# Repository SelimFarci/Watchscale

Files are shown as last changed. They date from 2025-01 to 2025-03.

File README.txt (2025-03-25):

# 🧭 DRO & DIVIDER Systems – Embedded Control Interface for Watchmaking Machinery

> Embedded systems project developed during a summer internship – ENSEA (2024)

## 📌 Project Summary

This project involved designing and prototyping two embedded control systems — a **Digital Read-Out (DRO)** interface and a **DIVIDER** motor control module — to modernize mechanical watchmaking machines, without altering their vintage aesthetic.

We developed a full-stack embedded application based on STM32 microcontrollers, including sensor data acquisition, user interface development (TouchGFX), real-time control of motors, and communication between devices.

> 💡 Non-confidential project – suitable for public sharing.

---

## 🔧 Key Features

### 🖥️ DRO System (Main Controller)
- 7” capacitive touchscreen interface
- Real-time display of axis positions (X/Y/Z)
- GUI with control functions: 
  - `ZERO`, `Ø/R`, `+/-`, spindle speed, and torque
- Interfaces: RL2IC sensors, UART, I2C, RS422

### ⚙️ DIVIDER System
- Dual stepper motor control:
  - Linear advance (motor 1)
  - Angular indexing (motor 2)
- Precision via screw/nut + endless screw systems
- Controlled from DRO board via I2C

---

## 🧠 Technical Stack

| Category | Tools / Technologies |
|---|---|
| Embedded Programming  | C, STM32CubeIDE, HAL drivers |
| GUI Development | TouchGFX |
| Microcontrollers | STM32F411xE (Nucleo), STM32H7 (Riverdi) |
| Communication | I2C, UART, RS422 |
| Signal Prototyping | Logic Analyzer, Oscilloscope, Putty |
| Hardware Design | KiCad (schematics), sensors, motors |
| Components | RS485 Click, UART Mux, Incremental encoders, NEMA 17, Riverdi 7" LCD |

---

## 🛠️ Main Contributions

✅ Designed and implemented a user-friendly GUI on STM32 using TouchGFX  
✅ Developed communication interfaces (I2C, UART, RS422) between boards and sensors  
✅ Integrated stepper motor drivers with PWM and direction control  
✅ Built functional hardware prototypes with debugging via logic analyzers  
✅ Collaborated directly with a non-technical client to translate mechanical requirements into embedded specs

---

## 📸 Screenshots

> See full PDF report with schematics, GUI designs and prototyping photos here:  
📄 [Rapport_de_projet_Watchscale.pdf](./Rapport_de_projet_Watchscale.pdf)

---

## 👨‍💻 Authors

- **Selim Farci** – Embedded Systems Engineering Student (ENSEA)  
- **Abdelkader Chambi** – Embedded Systems Engineering Student (ENSEA)  
- **Eyraud Michaël** – Internship supervisor and initiator of the project (Mécaniquement Vôtre)

---

## 🪪 License

This project is released under the **MIT License**.  
Note: proprietary hardware is subject to company use policies.

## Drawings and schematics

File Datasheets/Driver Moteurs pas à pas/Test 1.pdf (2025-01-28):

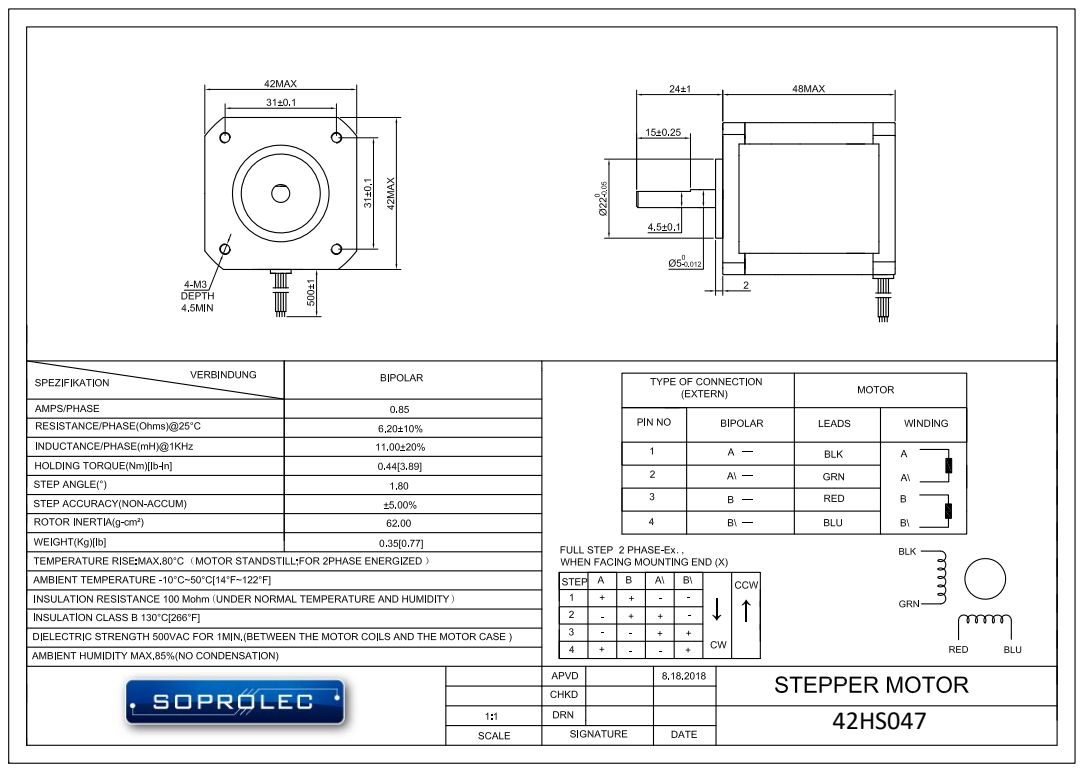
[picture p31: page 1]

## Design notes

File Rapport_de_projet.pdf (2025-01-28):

# 2A FISE Project Report

Development of a DRO and DIVIDER System

Selim FARCI, Abdelkader CHAMBI

June-August 2024

Interns: Selim Farci, AbdelKader CHAMBI Company Supervisor : Mr. Micha¨el EYRAUD University Supervisor : Mr. CHIPI

## Table of Contents

1 Introduction | 4
2 DRO and DIVIDER Systems | 5
3 SYSML and GANTT Diagrams | 7
4 Component selection | 9
5 Electrical schematic | 23
6 Graphical Interface Development | 24
7 Prototypes | 31
8 Challenges and Problem Solving | 44
9 Results and Discussions | 44
10 Conclusion | 44

10.1.1 Insufficient supervision and non-compliance with the requirements of the engineering

## 1 Introduction

### 1.1 Company Presentation

M´ecaniquement vˆotre, based in Switzerland, is a company managed by EYRAUD Michael. The company specialises in the overhaul of old industrial watchmaking systems, systems that are now coveted by various watch enthusiasts, such as collectors and watchmakers. EYRAUD Michael is a mechanic, which is why the company is first and foremost a workshop. During this project, we worked alongside other trainees, who themselves specialised in mechanics. The company does not have a CSR management system. It does, however, recycle as much as possible of its parcel boxes.

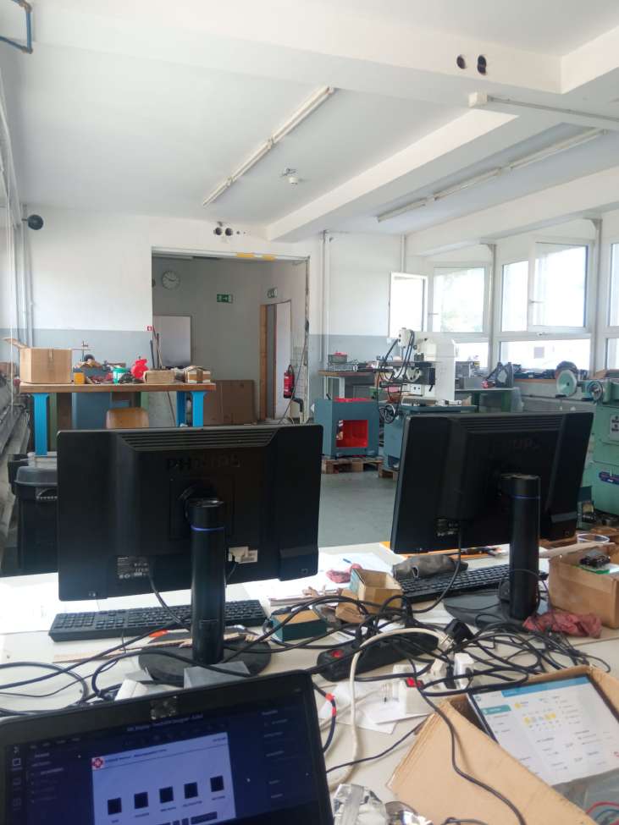
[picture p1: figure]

Figure 2: Increment sensors overview

The project assigned to us was part of this modernization effort, involving the development of a DRO system and a DIVIDER system. Although the entrepreneur was not an expert in electronics, he played a key role in financing the project and defining the requirements, which required a deep understanding of his expectations to translate these ideas into technical solutions.

### 1.2 Context and objective of the project

The objective of the project is to develop a ”DRO system and a ”DIVIDER system”.
The DRO system have to display and modificate values given by sensors and linear scales from a minimum 7” touch screen controller.
The DIVIDER system is a complementary system of the DRO system, he have to control 2 stepper motors to perform various functions.
This DRO system aims to facilitate the use of industrial watchmaking systems while preserving old industrial machines. These machines, which are highly sought after by watchmaking artisans, retain their vintage appearance as they are valuable collector’s items. Keep in mind that the price and industrial credibility are important factors for the development of this project.

## 2 DRO and DIVIDER Systems

### 2.1 The DRO system

The DRO system will be the control center and user interface panel with screen, control and switches, it have to run independently.
The system must be ready to control all other systems so the functions of all others systems must be programmed on the microprocessor.
The system must display with a graphical interface:
- Number of axes (values from RL2IC sensors)
– Function buttons - Spindle motor information.
Functions:
- ZERO: Set value to 0.
- Ø / R: Double value (Ø = Diameter) or reset to original (R = radius).
- + / -: Add or subtract a value (Show keyboard to give a value, apply, select axis).
- Spindle speed:
- Spindle torque:
- menu back

(a) Example of the graphical user interface of the MENU provided by the specifications document
(b) Example of the graphical user interface of the DRO provided by the specifications document

### 2.2 The DIVIDER system

The DIVIDER system will be a complementary system to the DRO system, Enabling control of 2 stepper motors to perform various functions.
Functioning : From the angular zero bridge and the current linear zero point. 1: Stepper motor No. 1 turns to drive a precision screw/nut system to perform a linear advance cycle including advance of a given value then return to the initial position. 2: Stepper motor No. 2 turns to drive a screw and endless wheel system, to perform angular indexing defined by a given number of divisions, applied to a given angular sector, from its current position to the next position. The angular position is controlled by an sensor (same as the DRO system) and a circular scale and must be adjusted corrected as necessary before starting a new cycle of linear motion motor 1.

Figure 4: Example of the graphical user interface of the DIVIDER provided by the specifications document

## 3 SYSML and GANTT Diagrams

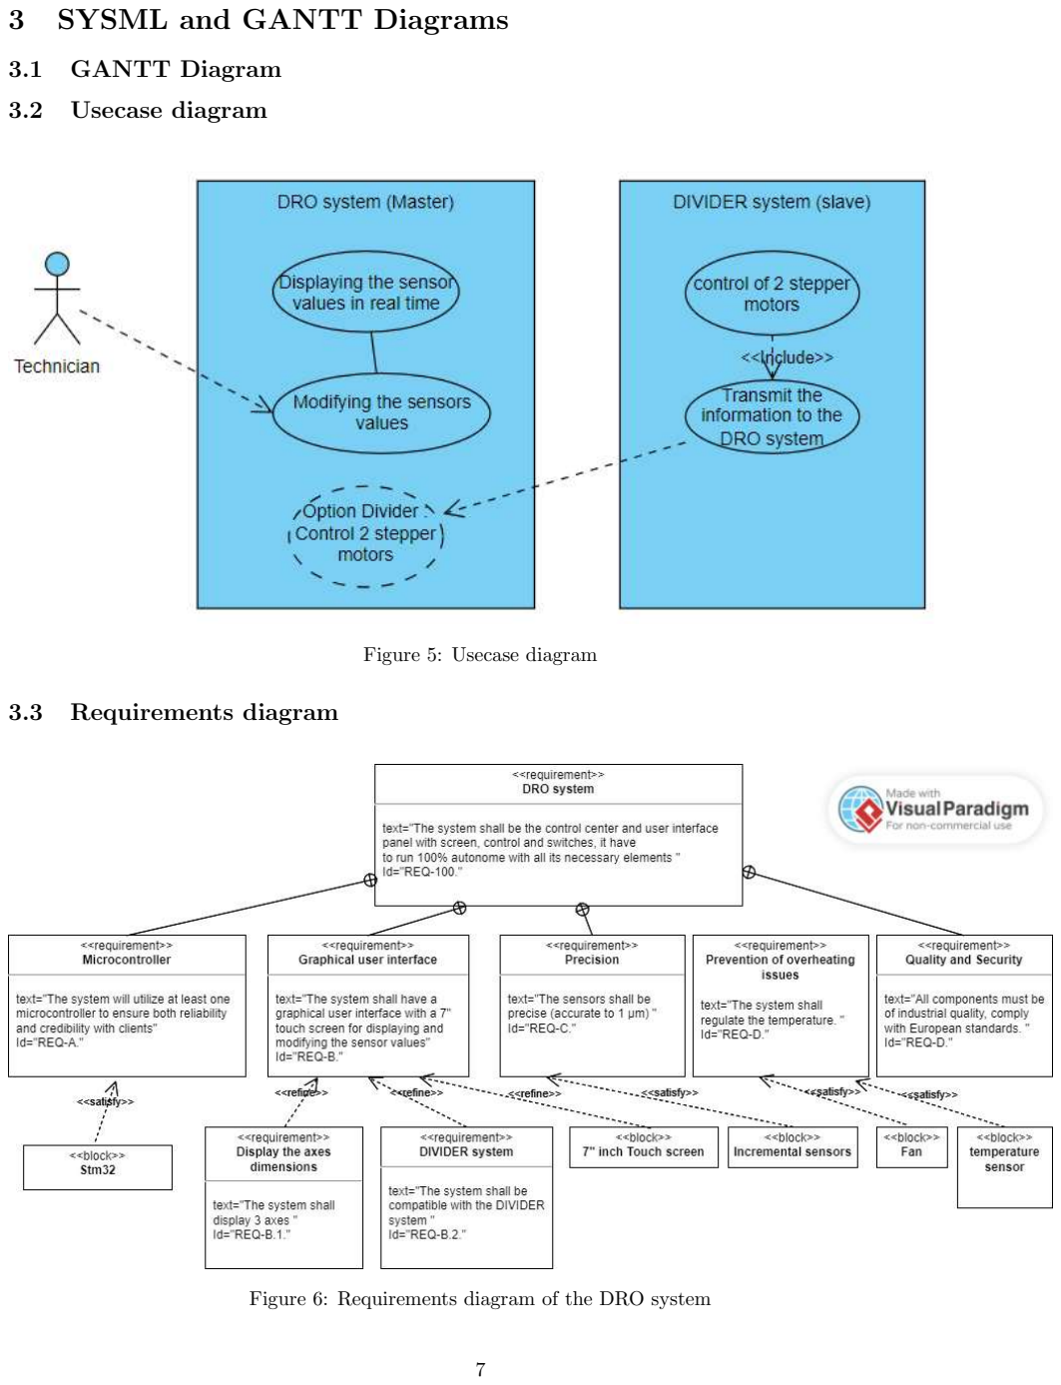
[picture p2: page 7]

### 3.1 GANTT Diagram

### 3.2 Usecase diagram

Figure 5: Usecase diagram

### 3.3 Requirements diagram

Figure 6: Requirements diagram of the DRO system

Figure 7: Requirements diagram of the DIVIDER system

### 3.4 Gantt diagram

## 4 Component selection

### 4.1 Choice of the micro-controller

It is important to choose a micro-controller with display capabilities in mind, because in this project the graphical user interface (GUI) is an important part of the project. We compare different technologies and screen display technologies to choose the best solution for our project while respecting the requirements. note : We didn’t compared the Arduino series because its industrial credibility wasn’t enough for the requirements.

Crit`eres | PLC | STMicroelectronics | Rasberry Pi
Microcontroller | Siemens S7, Allen Bradley, etc. | STM32 Series | Raspberry Pi series
Microcontroller’s software | TIA Portal, RSLogix | STM32CubeIDE | Raspberry Pi OS (Raspbian)
Graphical user in-terface (GUI) soft-ware | WinCC, Fac-toryTalk, GT Designer | TouchGFX | PyQt, Tkinter, Electron
programming lan-guage | Ladder Logic, FBD, ST | C, C++ | Python, C++, JavaScrip
suitable environ-ment | Industriel, Au-tomatisation lourde | Industriel, Automatisa-tion | Education, Proto- ´ typage, Domotique
type of screen | HMI Panels, Touch Screens | TFT LCD, Capacitive Touch Screens | HDMI, Capacitive Touch Screens
Price | High | Moderate | Moderate

Table 1: comparison between the different existing technologies with enough industrial credibility

We didn’t select the PLC technology because its price is too high and the system shall be easily integrable with other systems. Using a programmable logic controller (PLC) is not the right solution for our project. The Raspberry Pi has an advantage in graphical user interface because it is created for this aspect, but we don’t have the same adaptability in the hardware part as an STM32. Furthermore, we don’t even need an OS for our GUI.
The STM32 technology seems to be the best solution for our project because this technology respect all our requirements :
- the REQ-A and the REQ-D are respected because the STM32 series is famous for its reliability and durability in industrial environments. STMicroelectronics offers a wide range of microcontrollers suitable for various industrial applications, from simple process control to complex embedded systems.
- We can connect screens for programming GUIs respecting the REQ-B
-We can more easily transmit information from the DIVIDER system to the DRO system.

### 4.2 Display selection

Solutions | Screen | Product Details and comment | Price
Sol 1 | Waveshare 7” Ca-pacitive Touch | 1024x600, HDMI/USB, Cortex-M7, Moderate quality | 70 dollars
Sol 2 | Riverdi 7” (avec STM32H757 in-cluded) | High quality, TouchGFX is suitable be-cause it is software from STMicroelec-tronics, and the STM32 is integrated into the screen | 200 dollars
Sol 3 | Generic 7” TFT (ILI9488) | 800x480, SPI, Cortex-M4, Low quality | 35 dollars

Table 2: comparison between the different existing screens

The Riverdi solution seems to be the best for our project because its software environment is more adaptable to our microcontroller since it is a component from STMicroelectronics. By using all ST components, we will simplify the programming because the components will communicate more easily with each other. With this solution, the quality of the screen is guaranteed and the STM32 is already included in the screen, making the wiring easier.

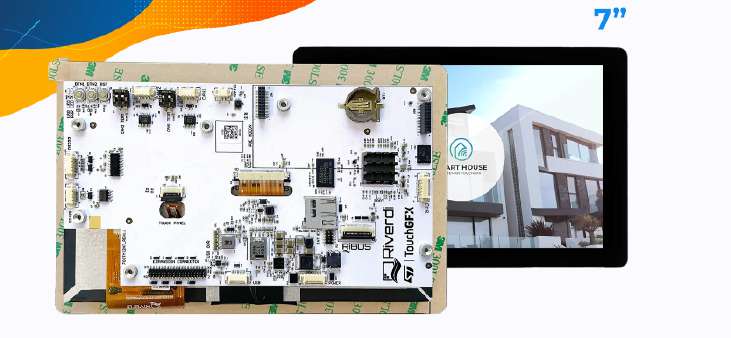
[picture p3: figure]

Figure 8: Riverdi screen (ref : RVT70HSSNWC00-B)

The Riverdi screen has 40 pins that can be used. These pins come from the STM32H7 (the STM included in the Riverdi). These pins have the following interfaces available:
- 2 x I2C
- 1 x UART
- 1 x USART
- 1 x SPI
- 1 x USB
- 7 x PWMs
- 2 x DACs (Digital-to-analog)
- 2 x ADCs (Analog-to-digital)
Each of the GPIO pins can be configured by software as output (push-pull or open-drain, with or without pull-up or pull-down), as input (floating, with or without pull-up or pull-down) or as peripheral alternate function. Most of the GPIO pins are shared with digital or analog alternate functions.
(a) Expansion connector pins schematic | (b) Expansion connector

Figure 9: Expansions connector

The power supply for this screen is between 8 and 48V.

### 4.3 Increment Sensor Selection

We need 4 sensors very precise, (accurate to 1 um). The sensor shall be indicate 3 positions (X,Y,Z) for the DRO system and an angular position for the DIVIDER system. We need so 4 sensors for respect this requirements. We selected Increment sensors because of its precision.

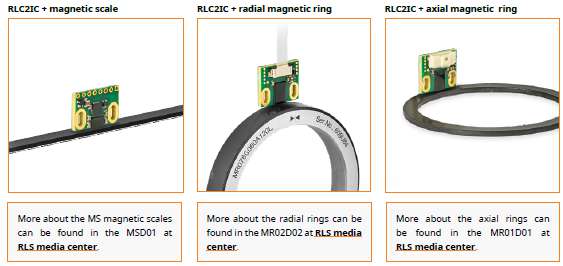
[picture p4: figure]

Figure 10: Increment sensors overview

We chose the reference below : RLC2ICA2D0DD0B00

(a) Increment sensors part numbering | (b) Increment sensors pins connections

Figure 11: Increment sensors available resolution

According to the Datasheet, the resolution is : 2um.
We have 8 outputs from an increment sensor : +5V, GND and 3 square-wave signals : A, B, Z and their inverted signals A–, B–, Z–.

(a) Increment sensors electrical connections | (b) Increment sensors pins connections

Figure 12: Increment sensors outputs

Signal A+ : Each signal has its complementary signal to reduce Electromagnetic Interference (EMI) and improve signal robustness, especially over long cables.
Signal A: The A signal is a square wave that changes state (high/low) at regular intervals when the encoder rotates.
Signal B: The B signal is a square wave that is phase-shifted by 90 degrees relative to the A+ signal. The 90-degree phase shift between A+ and B+ allows for the determination of the direction of rotation. If A+ leads B+, the rotation is in one direction, and if B+ leads A+, the rotation is in the opposite direction. Signal Z: The Z+ signal is a square wave that generates a single pulse per complete rotation of the encoder. The index signal (Z+) is used to provide an absolute reference for the position, allowing for re calibration or synchronization of the position to a known point.

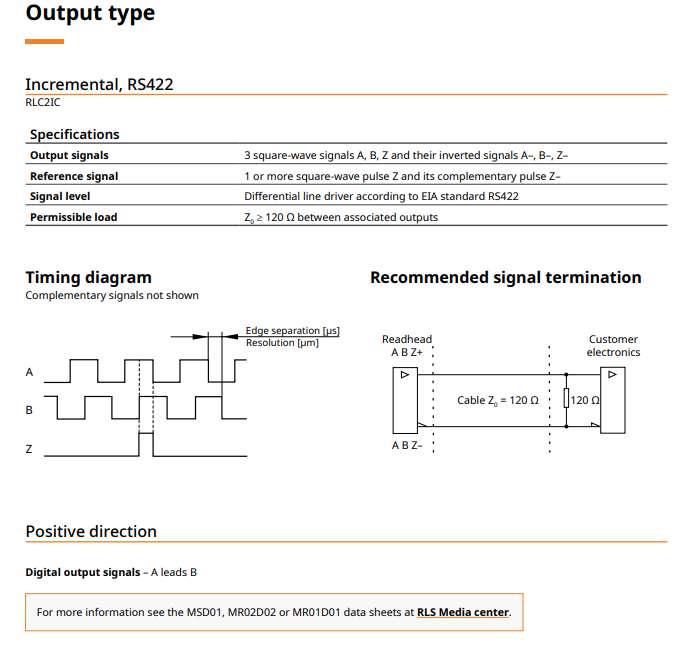
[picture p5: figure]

Figure 13: Increment sensors overview

The output type is the RS422 interface. We will process the signal A, B and Z on a microcontroller so we need to convert the RS422 interface to a micrcontroller communication (as UART, I2C, SPI, TTL, ect..). For that, we can use a RS422 Converter or an Incremental encoder.

### 4.4 Transeiver RS485/RS422 communication

The incremental sensor output signals are RS422 type signals.
The RS-422 protocol is designed for unidirectional serial communications, typically point-to-point or point-to-multipoint. An RS-422 transceiver can be either a transmitter or a receiver, but not both on the same channel. Typically, an RS-422 transmitter sends a differential signal on one pair of wires (A+ and A-), and multiple receivers can receive this signal by reading the voltage difference between A+ and A-. This configuration allows reliable transmission over long distances, up to 1200 metres, while being resistant to noise and interference. However, communication is strictly unidirectional between the transmitter and receivers.

Figure 14: Rs422 Drivers/receivers

The RS-485 protocol is a differential serial communication standard used in multidrop networks, enabling several devices to share the same communication bus. It can operate in two modes: half-duplex and full-duplex.
In half-duplex mode, communication is bidirectional but not simultaneous. This means that a device can either send or receive data at a given time, but not both at the same time. This mode uses a single pair of wires for transmission and reception, simplifying cabling and reducing costs, making it ideal for systems where simultaneity is not critical.
In full-duplex mode, communication is bidirectional and simultaneous. Each device can send and receive data at the same time, requiring two pairs of wires (one for transmission and one for reception). This mode is used in applications where fast, efficient communications are essential.
For an RS-485 transceiver to be compatible with an RS-422 protocol, it must be configured in half-duplex mode. This ensures that communication remains unidirectional and that the system behaves as expected by RS-422.
In our case, the direction of data transmission is from the sensor to the microcontroller as shown below:

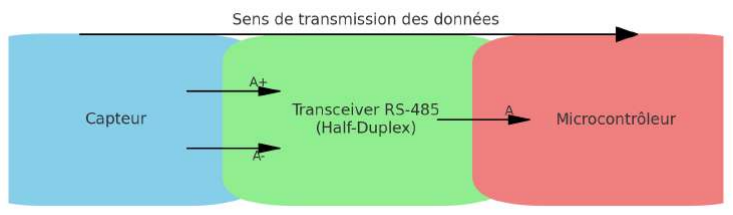
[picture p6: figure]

Figure 15: RS422 - Transmission data

We choose the RS485 transceiver : RS485 7 click from the manufacturer MIKROE.

Figure 16: Rs485 7 click pins

Figure 17: Rs485 7 click pins descriptions

Figure 18: Rs485 7 click pins table

To activate the RS485 transeiver in half-duplex mode, we will use the RX terminal to receive the data from the sensor and set the driver enable (DE) to 0. The RE will be set to 1.

### 4.5 UART Multiplexer

We have a problem with this way, because we have just one uart interface available on the riverdi expansion pins. So we need a multiplexer to receive the data. So we need a multiplexer to transmit all data on just one bus.

So for that we will use 2 boards of this component : UART MUX CLICK from the manufacturer MIKROE.

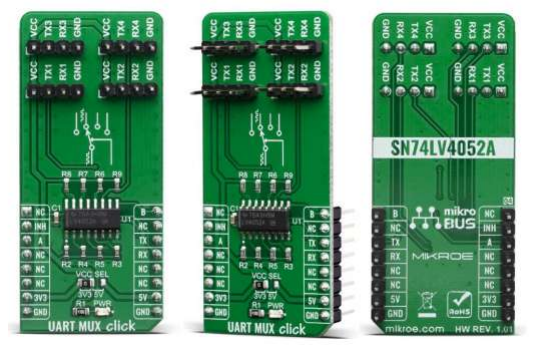
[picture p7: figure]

Figure 19: Multiplexer UART MUX CLICK

The UART Mux click is a Click board™ that switches the UART pins (RX and TX) from the mikroBUS™ to one of the four available outputs. It employs the SN74LV4052A, a Dual 4-Channel Multiplexer and Demultiplexer from Texas Instruments.

Figure 20: Multiplexer uart pins descriptions

HOW DOES IT WORK? labeled as A and B can be operated by 5V MCUs. The fourth control pin is labeled as EN pin, and it is used to enable the The active low Inhibit (INH) tri-state all the channels when high and when low, depending on the A and B inputs, one of the four independent input/outputs is connected to the UART communication pins.

### 4.6 Logic Analyzer

In this project we will be working with communication signals, so we need a logic analyser to simplify the data process on the prototype part. For that, we choose the logic analyzer shown below :

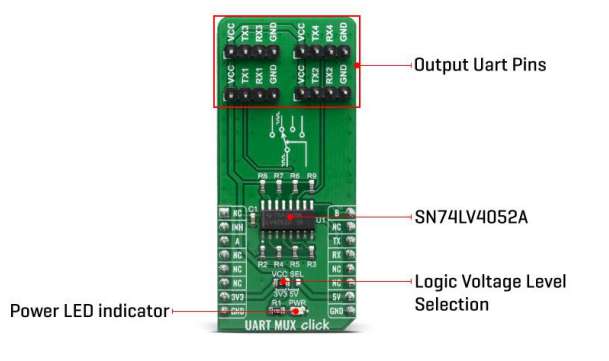
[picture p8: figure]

Figure 21: Logic Analyzer

We will use the software ”Logic 2”. This software is needed. With this Logic analyzer, we will can process the UART communication for the sensors and also the commnucation between the two boards (Riverdi and stm32F4).

### 4.7 Motor selection

According to the specifications, the stepper motor must be a Nema 17 type with a torque of 0.44 N.m and a good step angle accuracy (we will use 0.9°). We selected the WO-4209L-01P Lin Engineering motor respecting the requirements. The output current is 1.7A/phase and its supply voltage is 24V. (we will need this information for the driver).

Figure 22: Appearance of the Motor

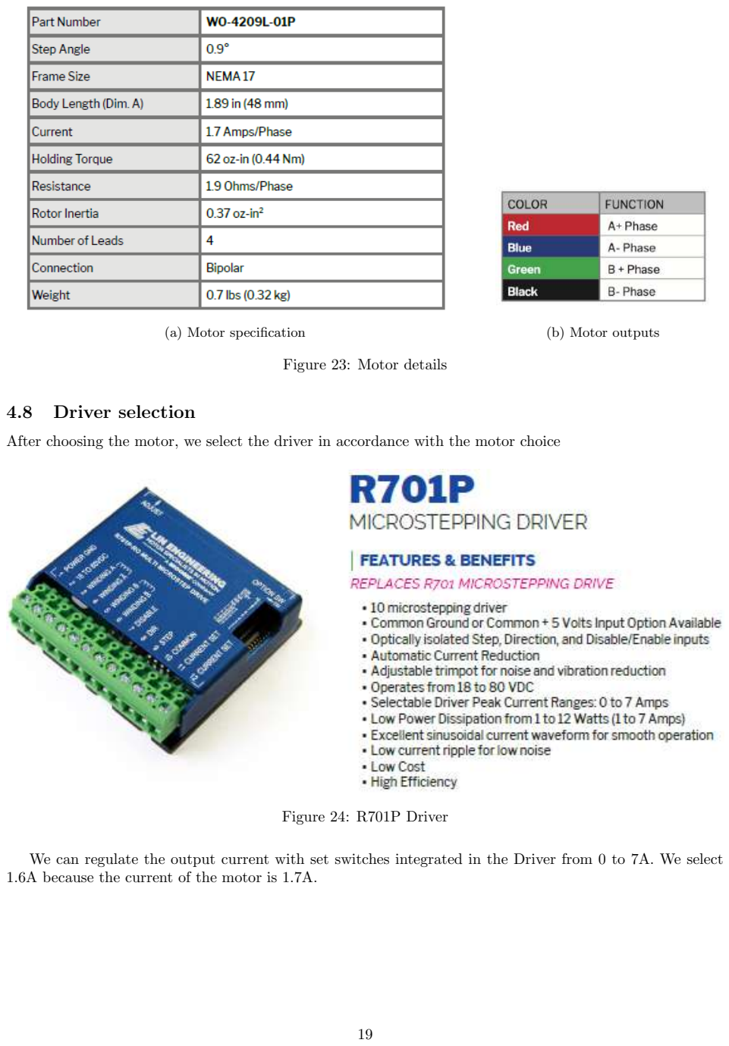
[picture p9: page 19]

(a) Motor specification | (b) Motor outputs

Figure 23: Motor details

### 4.8 Driver selection

After choosing the motor, we select the driver in accordance with the motor choice

Figure 24: R701P Driver

We can regulate the output current with set switches integrated in the Driver from 0 to 7A. We select 1.6A because the current of the motor is 1.7A.

(a) Driver option set switches for
regulate the output Current | (b) Driver outputs

Figure 25: Driver details

### 4.9 STM32F411xE

We decided to use an STM32 NUCLEO microcontroller (specifically the STM32F411xE) because, after calculating the number of inputs/outputs used by the various components and the interface needed, we realised that the Riverdi’s expansion connector did not have enough pins and interfaces to process our components.. So we decided to use an STM32 NUCLEO because of its small size and it’s enough for our application.

Figure 26: Appearance of the STM32F4 NUCLEO

This microcontroller has I2C interface pins to communicate with the STM32H7 (included on the Riverdi board). Pins PB6/PB10/PA8 are for the SCL signals and PB7/PB9/PB4 are for the SDA signals.

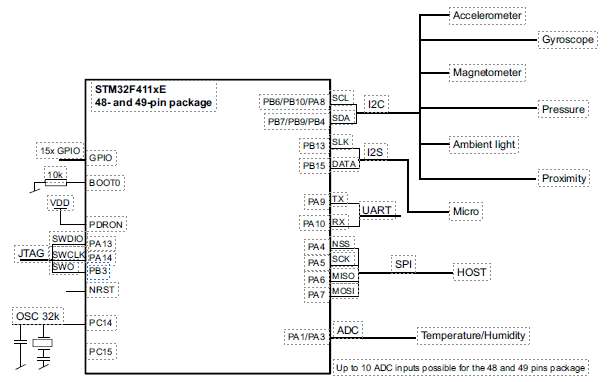
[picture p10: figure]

Figure 27: STM32F4 Datasheet I2C Interface Pins

### 4.10 Power supply selection

The power supply will supply the DRO and the DIVIDER with 24V. We need to identify the power and current consumption of each component from their datasheets.
We have get this information in our excel file (on the ”Electrical characteristics” page), which you can download here: Download Excel File (https://docs.google.com/spreadsheets/d/1DbypNOv9fv3KTsBZ1phE5vJ9S48CBGTn/edit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)
According to our calculations from the Excel table, the maximum power consumption of our system (if everything is operating simultaneously at full power) is 105W with a current of 5.1A. Therefore, we need an oversized system compared to these values.
We selected the EDR-150-24 Mean Well power supply, which takes an input of 230VAC and provides an output voltage of 24VDC. The maximum power that this power supply can provides is 156W, which is 1.5 times more than necessary, and it can deliver up to 6.5A (providing a margin of 1.5A).

Figure 28: Appearance of the power supply

Figure 29: Specification of the power supply

## 5 Electrical schematic

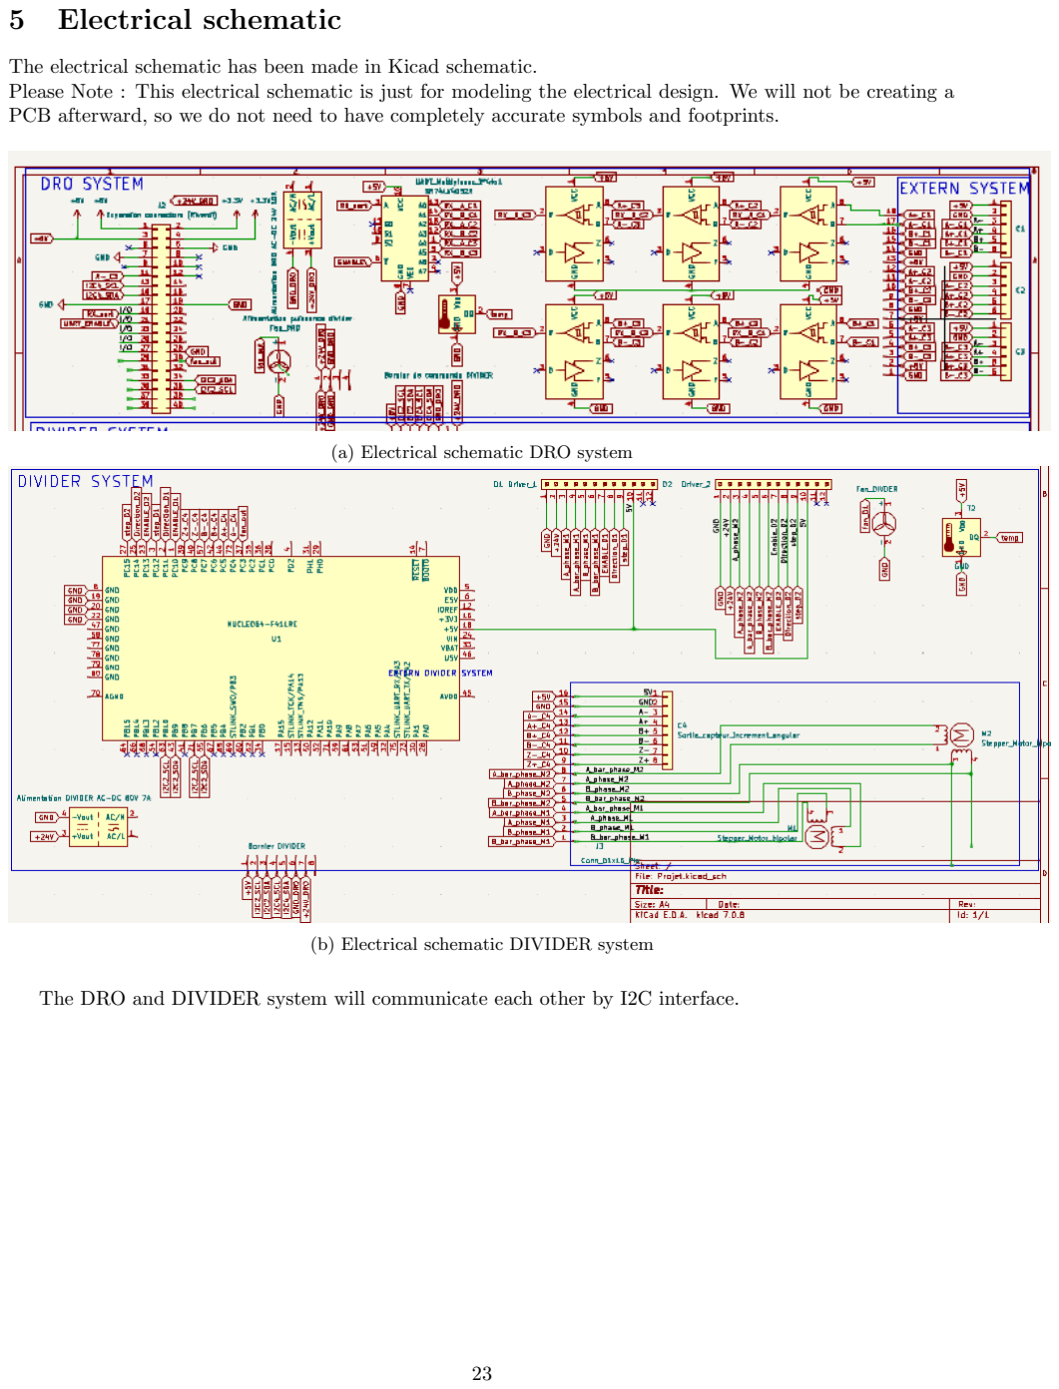
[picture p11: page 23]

The electrical schematic has been made in Kicad schematic.
Please Note : This electrical schematic is just for modeling the electrical design. We will not be creating a PCB afterward, so we do not need to have completely accurate symbols and footprints.
(a) Electrical schematic DRO system
(b) Electrical schematic DIVIDER system

The DRO and DIVIDER system will communicate each other by I2C interface.

## 6 Graphical Interface Development

### 6.1 User Interface Design

The graphical interface of the project was developed using TouchGFX, a powerful tool for creating embedded user interfaces on STM32 microcontrollers. The primary goal of the graphical interface was to allow smooth and intuitive interaction with the DRO (Digital Readout) system, enabling real-time display and modification of X, Y, and Z axis values.

### 6.1.1 MENU Screen

The user interface was designed with the end users in mind, who will operate the DRO and Divider systems. The main interface includes several screens dedicated to different functions:

Figure 31: SPLASHMENU Graphical Interface

### 6.1.2 DRO Screen

Displays axis values, spindle speed, torque, and functions such as axis zeroing, value doubling, and value addition or subtraction.

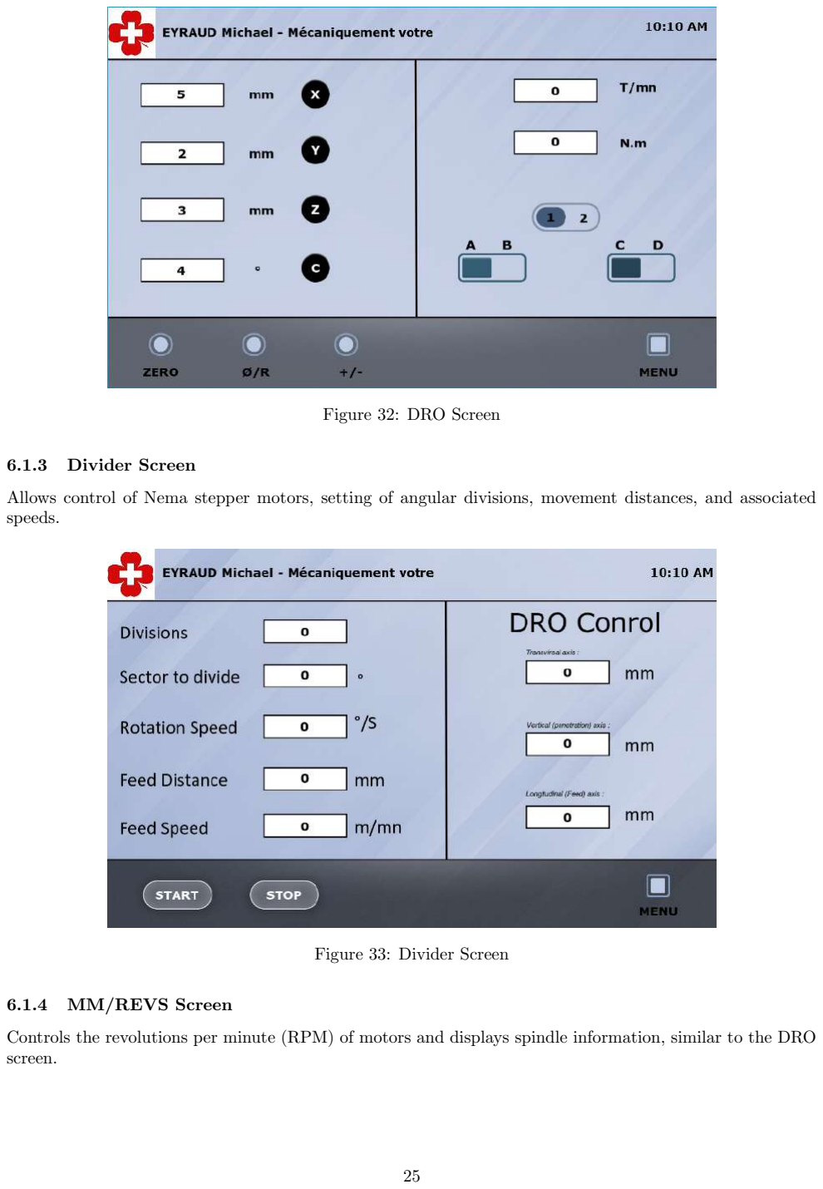
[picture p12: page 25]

Figure 32: DRO Screen

### 6.1.3 Divider Screen

Allows control of Nema stepper motors, setting of angular divisions, movement distances, and associated speeds.

Figure 33: Divider Screen

### 6.1.4 MM/REVS Screen

Controls the revolutions per minute (RPM) of motors and displays spindle information, similar to the DRO screen.

Figure 34: MM/REVS Screen

### 6.2 Impl´ementation avec TouchGFX

The graphical interface was implemented using TouchGFX within the STM32CubeIDE development environment. Key steps in the development included:

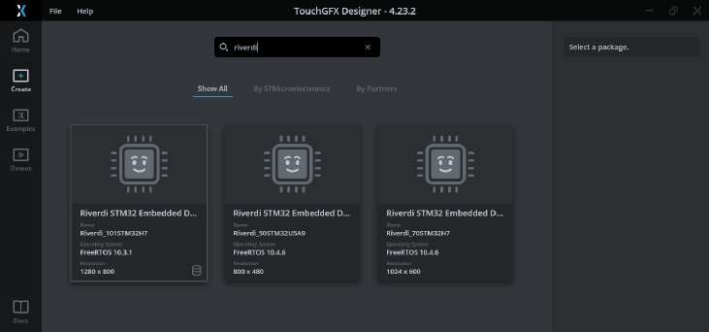
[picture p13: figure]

Figure 35: choice of interface

- Initial Configuration: The TouchGFX project was successfully configured in STM32CubeIDE, including the integration of the TouchGFX library, configuration of the STM32F7 board, and the TFT display.

Figure 36: configuration in STM32CubeIDE

- Screen Development: The main screens of the interface, including the DRO screen, were created in TouchGFX Designer. Graphic elements such as TextAreas, buttons, and progress bars were added and configured.

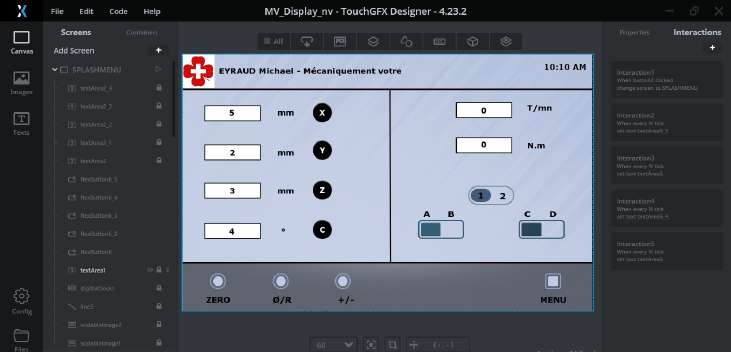
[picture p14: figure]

Figure 37: Graphic elements added and configured

- Logic Implementation: The code to update the X, Y, and Z axis values was partially implemented in the DROPresenter.cpp and DROView.cpp files.

Figure 38: Logic Implementation

- Simulation: Simulation attempts were made successfully.

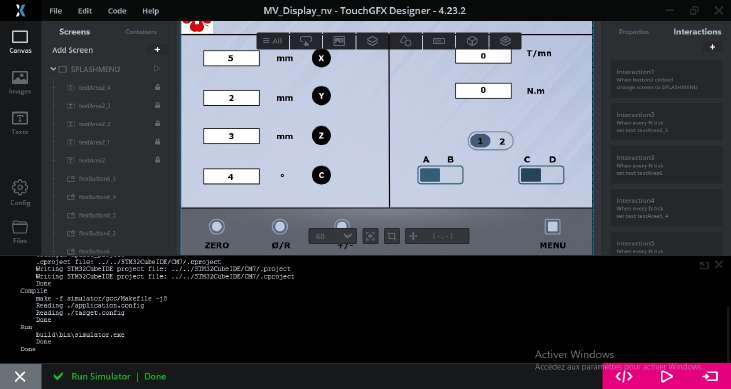
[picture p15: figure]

Figure 39: Simulation

Figure 40: Implementation of the graphical interface

### 6.3 Button Implementation

During the development of the graphical interface, one of the key features implemented was the functionality of various buttons, such as the ”Zero” button, which resets the values of the axes to zero. This feature is essential for the operation of the DRO system as it allows the user to recalibrate the machine quickly. During the development of the graphical interface, one of the key features implemented was the functionality of various buttons, such as the ”Zero” button, which resets the values of the axes to zero. This feature is essential for the operation of the DRO system as it allows the user to recalibrate the machine quickly.

- Zero Button: The ”Zero” button was successfully implemented, enabling users to reset the X, Y, and Z axis values to zero with a single click. This required careful handling of the underlying code to ensure that the reset operation was synchronized with the hardware and reflected immediately on the display.

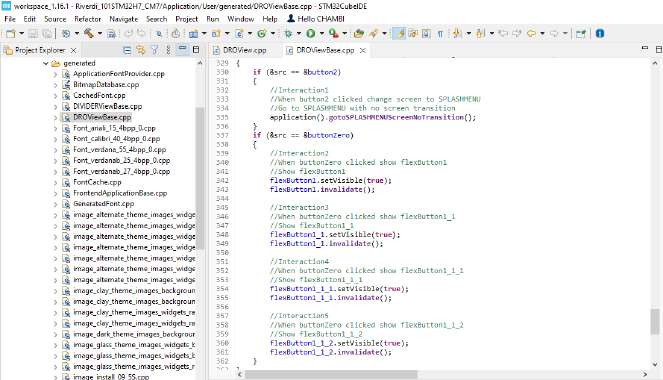
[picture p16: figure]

Figure 41: Implementation of Zero Button

- Other Buttons: In addition to the ”Zero” button, other critical buttons, such as those for doubling the values or adding/subtracting specific measurements, were also implemented. Each button’s function was mapped to specific operations in the code, ensuring that they performed as expected when pressed.

### 6.3.1 Challenges in Code Implementation

While implementing these buttons, several challenges were encountered, particularly in getting the buttons to interact correctly with the underlying system:
Complexity in Event Handling: The main challenge was handling the events triggered by these buttons, especially in ensuring that each button’s function was executed without causing delays or conflicts in the system.
Code Debugging: Debugging the code associated with these buttons was also challenging. There were instances where the buttons did not respond as expected, often due to issues with how the events were being managed in the code. This required thorough testing and debugging to resolve.

## 7 Prototypes

### 7.1 Communication between the boards Riverdi and stm32F4

It exist differents way to communicate between two microcontrollers: - UART (USART) - SPI (Serial Peripheral Interface) - I2C (Inter - Integreted Circuit)
We compare the different way to communicate with the both boards
Criteria | UART | SPI | I2C
Advantages | Simplicity of coding, com-monly used, fewer pins re-quired than SPI. Both di-rections data transmit. | Duplex communication, speed, flexibility, no collision, practical for displaying sensor informa-tion. | Uses only 2 wires, sup-ports multiple masters, ACK/NACK bits, widely used.
Disadvantages | No acknowledgment bits, slower than SPI. | Requires more pins, lim-ited to short distances, no acknowledgment proto-cols, often a single master, compatibility issues with different operation modes. | Slower than SPI, protocol overhead.

Table 3: Comparison between the different existing technologies with sufficient industrial credibility

We will develop the inter-integrated circuit (I2C) . For this, we will create a buffer to transmit the data to the board.
I2C is a two-wire serial communication system used between integrated circuits which was originally created by Philips Semiconductors back in 1982. The I2C is a multi-master, multi-slave, synchronous, bidirectional, half-duplex serial communication bus. SDA (Serial Data) is the line on which master and slave send or receive the information (sequence of bits). SCL (Serial Clock) is the clock-dedicated line for data flow synchronization.

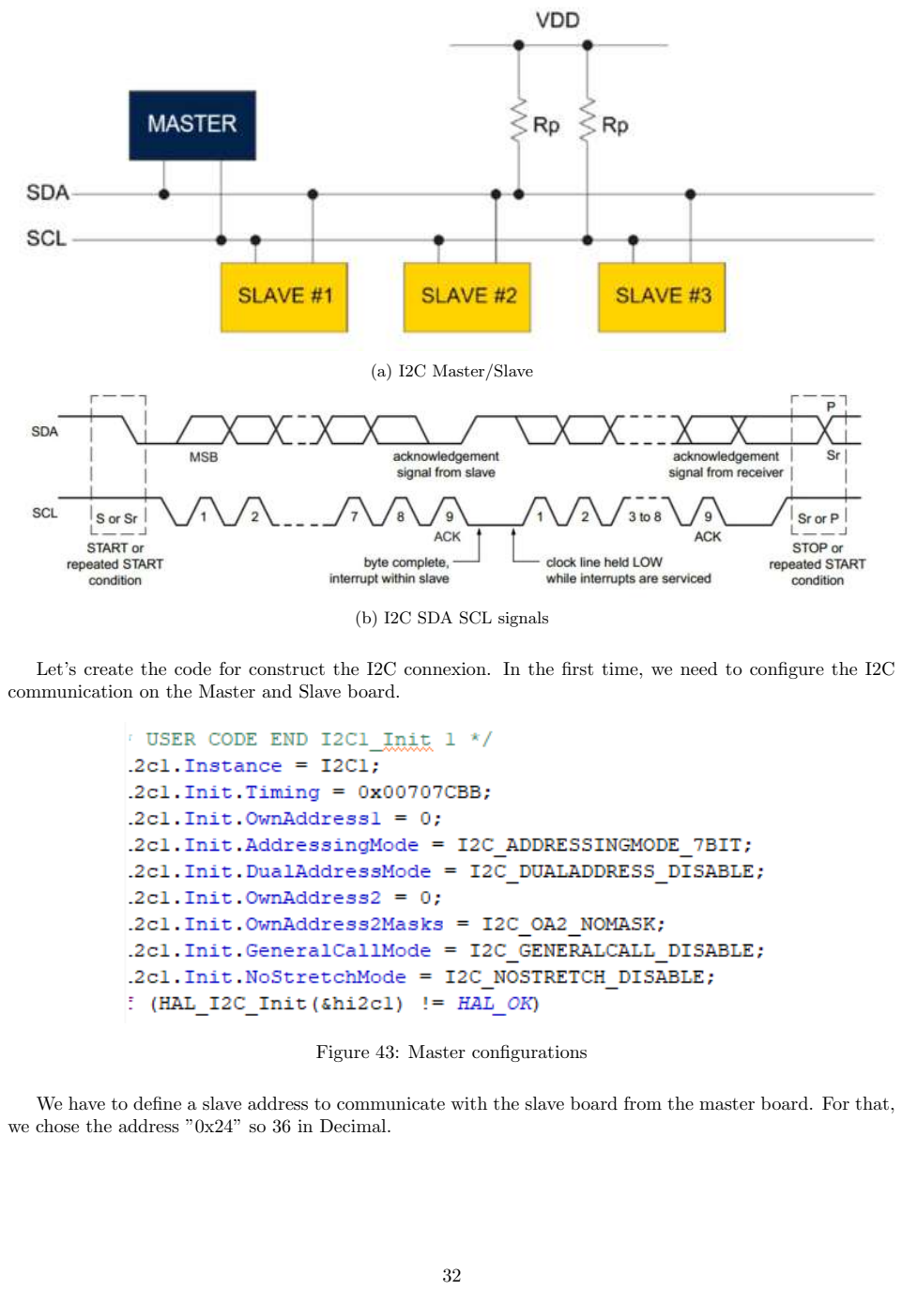
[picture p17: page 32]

(a) I2C Master/Slave
(b) I2C SDA SCL signals

Let’s create the code for construct the I2C connexion. In the first time, we need to configure the I2C communication on the Master and Slave board.

Figure 43: Master configurations

We have to define a slave address to communicate with the slave board from the master board. For that, we chose the address ”0x24” so 36 in Decimal.

Figure 44: Master configurations

For that, we need just to send a buffer with the code shown bellow :

(a) Electrical schematic DRO system
(b) Electrical schematic DIVIDER system

Start Condition (S) Stop Condition (P) Repeated Start (Restart) Condition (Sr) Acknowledge ACK (A) Not Acknowledge NACK (/A)

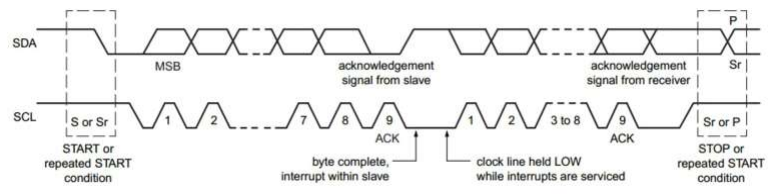
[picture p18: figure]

Figure 46: I2C SDA and SCL chronogram

(a) Oscilloscope : SDA (yellow) and SCL signals (rose)
(b) Electrical schematic DIVIDER system

### 7.2 UART communication

We will program a uart receiver for process the output signals of the Incremental sensors. In the first time, we will just create a simple UART communication for understand how it is works. For that, we will also send a buffer from the Riverdi and receive it in the stm32F4 board. We chose pins for the UART master communication.

Figure 48: UART pins

For that, I create in the Master board a file ”uart.c” :

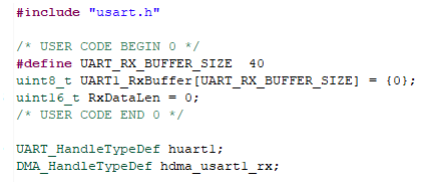
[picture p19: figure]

Figure 49: UART sending buffer

We configure the UART master configurations.

Figure 50: UART configurations

We do the same thing but with the slave side.

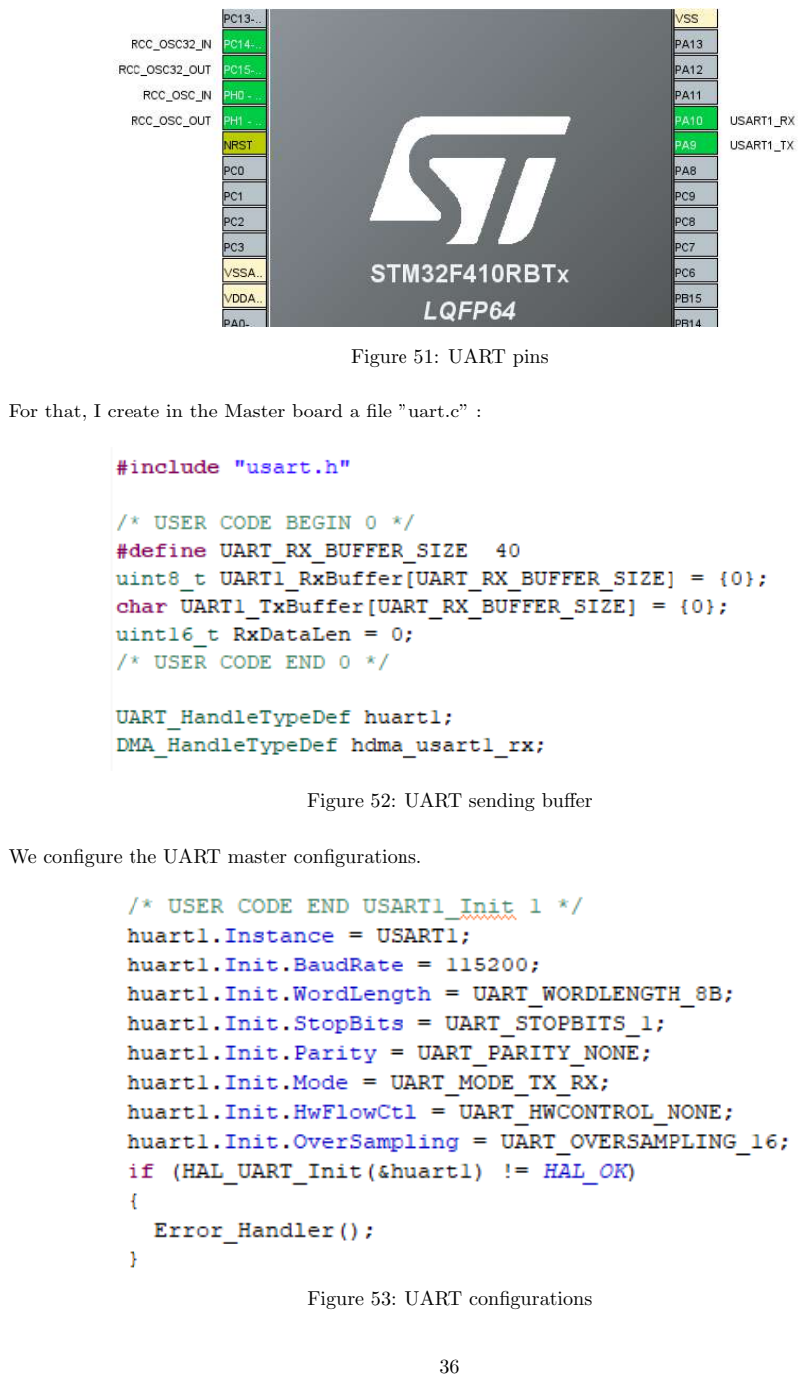
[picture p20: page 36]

Figure 51: UART pins

For that, I create in the Master board a file ”uart.c” :

Figure 52: UART sending buffer

We configure the UART master configurations.

Figure 53: UART configurations

We will now watch on the logic analyzer if it is works. For that, we do the schematic shown below :

Figure 54: UART wiring

For receive the buffer data, we had a problem with the logic anlayzer, so we used a uart ttl to usb device with the Putty software :

We write on the sending buffer ”Hello from the Master” and we will check if we receive correctly the information.

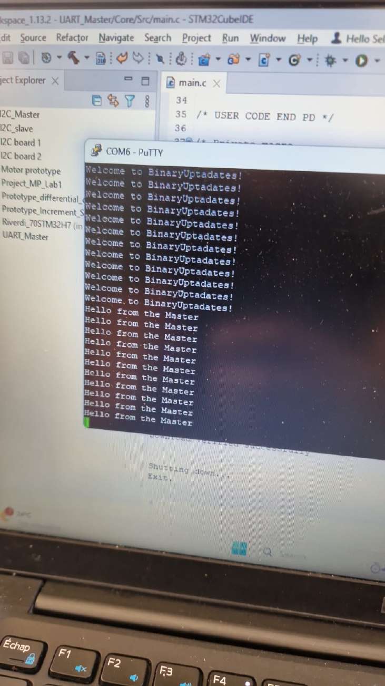
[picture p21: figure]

Figure 55: UART to usb device

We receive correctly the receive information so the prototype works correctly.

### 7.3 Motor prorotype

We generate code to control the drivers. To do this, we’re going to generate the ‘STEP’ (PWM signal), ‘ENABLE’ and ‘DIRECTION’ control signals. We use the register block to create the PWM signal. First we need to know some formulae.

Figure 56: Formules des timers

TIM1 est li´e `a APB2. On identifie : APB TIM clock = 100 MHz.

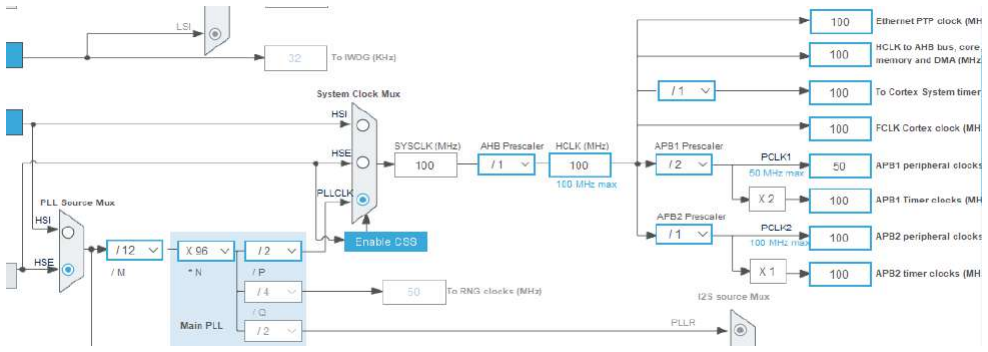
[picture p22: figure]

Figure 57: Configuration de l’horloge

TIM clock = APB TIM clock / PRESCALER
TIM clock = 100 Mhz / 100 = 1 Mhz Donc on param`etre PRESCALER `a : 100-1 (= 99) Frequency = 1 Mhz / ARR Frequency = 1Mhz / 100 = 10 kHz

Figure 58: Configuration du TIMER 1

Figure 59: Formules des timers

On g´en`ere ´egalement les signaux ”ENABLE” et ”DIRECTION” qui sont des signaux binaires.

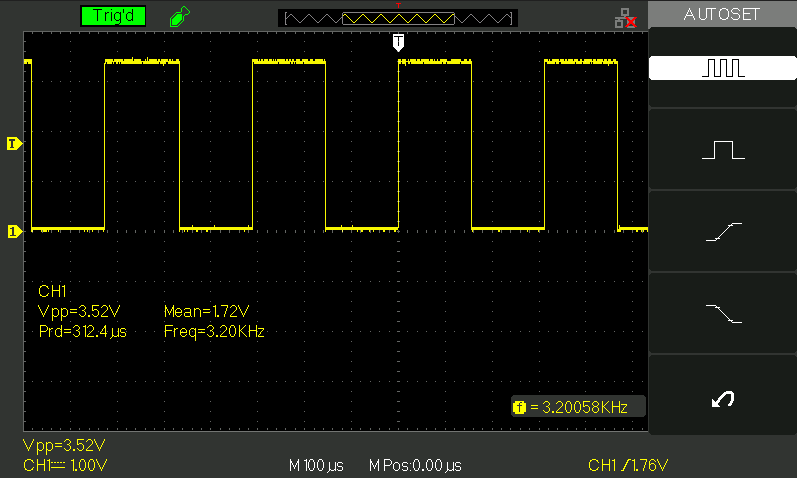
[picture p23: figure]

Figure 60: Visualisation de ”STEP”

We generate a code that will control the drivers. For that, we will, generate signals from the microcontroller for the Direction Input, and stop input. We use block from the register for create PWM signals.
We create a motor prototype for testing the control motors part
We need to know this formulas:
Le timer 1 is conntected `a APB2 TIM clock = APB TIM clock / PRESCALER TIM clock = 100 Mhz / 100 = 1 Mhz Frequency = 1 Mhz / ARR Frequency = 1Mhz / 100 = 10 kHz
The prototype system works well.

### 7.4 Increment sensor prototype

We received a sensor without an exact reference, so the first step was to identify each of the signals in order to know their functions and then use them.
Signal A+ : gray wire
Each signal has its complementary signal to reduce Electromagnetic Interference (EMI) and improve signal robustness, especially over long cables.
Signal A-: yellow wire The A+ signal is a square wave that changes state (high/low) at regular intervals when the encoder rotates.
Signal B+: Rose wire
The B+ signal is a square wave that is phase-shifted by 90 degrees relative to the A+ signal. The 90-degree phase shift between A+ and B+ allows for the determination of the direction of rotation. If A+ leads B+, the rotation is in one direction, and if B+ leads A+, the rotation is in the opposite direction. Signal B-: brown wire. The B- signals is the opposition of B+ wire.
The first time we use a data logic analyser with Logic 2 software (from salae). We connect A+;A-,B+,Bto the data logic analyser to check the signals. We check the signals without moving the sensor.

Figure 61: A+;A-;B+;B- inputs

Now, we move the sensor and along the magnetic scale.

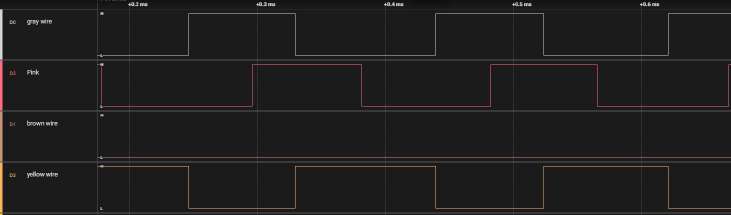
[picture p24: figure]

Figure 62: A+;A-;B+;B- inputs moving the sensor along the magnetic scale

All signals are correct.
We can now connect the signals to the rs485 transeiver. We had a problem in the receiving component and did’t have time enough for done this prototype.
1 : Green +5V 2 : X 3 : X 4 : White 5 : red 6 : Yellow 7 : gray 8 : Brown
Jaune et blanc mˆeme signal si brown = GND Rose et gris : mˆeme signal
La communication A+, A-, B+ et B- s’appel une communication RS422. Nous utilisons un encoder afin de traiter les signaux.

## 8 Challenges and Problem Solving

Several challenges were identified during development:

- Compilation Errors: Compilation errors were mainly due to missing text identifiers in DROView.cpp and the use of outdated or unsupported methods.
- Text Mapping Issues: Mapped texts were not correctly recognized, leading to additional errors during compilation.
- Simulation Issues: Due to the aforementioned errors, simulation could not be successfully executed, making visual validation of the interface difficult.
- Error Correction: It is necessary to correct the current errors by replacing incorrect text identifiers and using appropriate methods for the TextArea class.
- Interface Finalization: Complete the implementation of the axis value update functions in DROView and DROPresenter.
- Testing and Validation: After correcting the errors, the simulation must be executed to validate the interface and its functionality.
- Optimization and Debugging: Resolve any remaining errors or functional issues and optimize the code for smooth performance on the target hardware.

## 9 Results and Discussions

The final results demonstrate that the graphical interface is capable of effectively handling the assigned tasks, despite the challenges encountered during development. The user interface is intuitive, responsive, and integrates well with other systems, providing a complete solution for machine control.

## 10 Conclusion

### 10.1 astonishment report

10.1.1 Insufficient supervision and non-compliance with the requirements of the engineering assistant placement

During my work placement as an assistant engineer, I was surprised by the lack of adequate technical supervision. My tutor, Michael Eyraud, is a mechanic and didn’t have the necessary skills to supervise a project requiring expertise in electronics. Abdel and I, as trainees specialising in this field, had to carry out our project completely independently, without the support of a qualified engineer. Not only is this an unusual situation, but it does not comply with the requirements for assistant engineer traineeship.

### 10.1.2 Inappropriate management of trainees and overloading of the tutor

As the company’s only employee, the placement tutor had to manage 8 trainees at the same time, all of whom were assistant engineers. This overload resulted in ineffective management and inadequate supervision, which is particularly serious in the context of an engineering assistant placement, where specific and rigorous technical supervision is required.

### 10.1.3 Harassment and blackmail of trainees

During this placement, we observed various forms of harassment and blackmail by the tutor towards several trainees. We could cite dozens of examples of moral harassment, all of which have been documented, but that’s not the purpose of this report today.

### 10.2 Conclusion

This internship allowed us to develop a user interface for a DRO system using differents technicals softwares such as stm32cubeIDe, TouchGFX, Logic 2 and more. Through this experience, we was able to enhance my skills in system engineering and software development while addressing technical challenges related to real-time sensor integration.
In summary, this experience has been enriching and has prepared me for the technical and professional challenges we will face in our careers.

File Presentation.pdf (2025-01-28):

## Master’s 1 Project Presentation

Development of a DRO and DIVIDER System

Interns: Selim Farci, AbdelKader CHAMBI Company Supervisor: Mr. Michaël EYRAUD University Supervisor: Mr. CHIPI

## Sommaire

Introduction
Cahier des charges
Choix des composants
Choix du microcontroleur
Choix de l’écran pour l’interface graphique Choix du Moteur
Choix du Driver
STM32F411xE
Alimentation
Schéma électrique
Interface Graphique
Développement des prototypes Prototype I2C
Prototype Moteurs
Prototype capteur à Incrementation Conclusion et suite du projet

# Introduction

## Contexte et objectif du projet

Ce système DRO et DIVISER vise à faciliter l’utilisation des systèmes horlogers industriels tout en préservant les anciennes machines industrielles. Ces machines, très recherchées par les artisans horlogers, conservent leur aspect vintage car ce sont des objets de collection de grande valeur. N’oubliez pas que le prix et la crédibilité industrielle sont des facteurs importants pour le développement de ce projet.
- Le système DRO doit afficher et modifier les valeurs fournies par des capteurs et des échelles linéaires à partir d’un contrôleur à écran tactile d’au moins 7”.
- Le système DIVIDER est un système complémentaire du système DRO, il doit contrôler 2 moteurs pas à pas pour effectuer diverses fonctions.

## Le système DRO

Le système DRO sera le centre de contrôle et le panneau d’interface utilisateur avec écran, contrôle et interrupteurs, il doit fonctionner de manière autonome.
- Affichage avec interface graphique : nombre d’axes, boutons de fonction, information sur le moteur de broche.
- Fonctions : ZERO, Ø / R, + / -, vitesse de la broche, couple de la broche, retour au menu.


Figure: Interface graphique du système DRO

## Le système DIVIDER

Le système DIVIDER complémente le système DRO en permettant le contrôle de 2 moteurs pas à pas pour des fonctions variées.
- Cycle d’avance linéaire : rotation du moteur pas à pas No. 1.
- Indexation angulaire : rotation du moteur pas à pas No. 2.

Figure: Interface graphique du système DIVIDER

# Cahier des charges

## Diagramme de cas d’utilisation


Figure: Diagramme de cas d’utilisation

## Diagrammes de exigences du DRO


Figure: Diagramme d’exigences du système DRO

## Diagrammes d’exigences du système DIVIDER


Figure: Diagramme de exigences du système DIVIDER

# Choix des composants

## Choix du microcontrôleur

Nous avons comparé différentes technologies pour choisir la meilleure solution pour notre projet.

Critères | PLC | STM32 | Raspberry Pi
Microcontrôleur | Siemens S7 | STM32 Series | Raspberry Pi series
Langage de programmation | Ladder Logic | C, C++ | Python, C++
Environnement adapté | Industriel | Industriel | Education ´
Type d’écran | HMI Panels | TFT LCD | HDMI
Prix | Elevé ´ | Modéré | Modéré

Table: Comparaison des microcontrôleurs

## Choix de l’écran

Solution | Ecran ´ | Détails du produit | Prix
Sol 1 | Waveshare 7” | 1024x600, HDMI/USB | 70 dollars
Sol 2 | Riverdi 7” | Haute qualité, STM32 intégré | 200 dollars
Sol 3 | Generic 7” TFT | 800x480, SPI | 35 dollars

Table: Comparaison des écrans

Le choix s’est porté sur la solution Riverdi en raison de sa qualité et de son intégration facile avec le microcontrôleur STM32.

## Visualisation de l’écran Riverdi 7 pouces


Figure: Ecran Riverdi (ref : RVT70HSSNWC00-B)

## Caractéristiques techniques de l’écran

L’écran du Riverdi possède 40 broches qui peuvent être utilisées. Ces broches proviennent du STM32H7 (le STM inclus dans le Riverdi). Ces broches disposent des interfaces suivantes :
- 2 x I2C
- 1 x UART
- 1 x USART
- 1 x SPI
- 1 x USB
- 7 x PWMs
- 2 x DACs (Digital-to-analog)
- 2 x ADCs (Analog-to-digital)
On utilisera une des deux communication I2C pour le projet.

## Choix de l’écran


Figure: Riverdi screen (ref : RVT70HSSNWC00-B)

L’ecran doit s’alimenter avec une tension comprise entre 8 et 48V.

## Choix du Moteur

Selon les spécifications, le moteur pas à pas doit être de type Nema 17 avec un couple de 0,44 N.m et une bonne précision de l’angle de pas (nous utiliserons 0,9°). Nous avons choisi le moteur WO-4209L-01P Lin Engineering en respectant les exigences. Le courant de sortie est de 1,7A/phase et la tension d’alimentation est de 24V (nous aurons besoin de ces informations pour le pilote).

## Caractéristique technique du moteur

0.4

## Choix du driver

- Driver R701P pour contrôler les moteurs pas à pas.


Figure: Alimentation Mean Well

## Caractéristique technique du driver


Figure: Driver outputs | 20 / 52

## Caractéristique technique du driver


Figure: Driver option set switches

## Caractéristique technique du driver

Nous avons décidé d’utiliser un microcontrôleur STM32 NUCLEO (STM32F411xE) car, après avoir calculé le nombre d’entrées/sorties utilisées par les différents composants, nous nous sommes aperçus que le nombre de pins du Riverdi était insuffisante.pour l’ensemble du système.

Cela rend également assez indépendant le système DIVIDER.

Nous avons choisis ce microcontroller pour sa petite taille.

## stm32F411xE


Figure: stm32F411xE

## Caractéristique technique du driver

Ce microcontrôleur possède des broches d’interface I2C pour communiquer avec le STM32H7 (inclus sur la carte Riverdi). Les broches PB6/PB10/PA8 sont destinées aux signaux SCL et PB7/PB9/PB4 aux signaux SDA.

Figure: stm32F4 I2C pins

## Choix de l’alimentation

L’alimentation alimentera le DRO et le DIVIDER en 24V.

Nous devons identifier la consommation de puissance et de courant de chaque composant à partir de leurs fiches techniques.

Nous devons identifier la consommation de puissance et de courant de chaque composant à partir de leurs fiches techniques.

La consommation électrique maximale de notre système (si tout fonctionne simultanément à pleine puissance) est de 105W avec un courant de 5,1A.

Nous avons choisi l’alimentation EDR-150-24 Mean Well, qui prend une entrée de 230VAC et fournit une tension de sortie de 24VDC.La puissance maximale que cette alimentation peut fournir est de 156 W, soit 1,5 fois plus que nécessaire. fois plus que nécessaire, et elle peut délivrer jusqu’à 6,5A (avec une marge de 1,5A).

## Alimentation EDR-150-24 Mean Well


Figure: Power supply

## Alimentation EDR-150-24 Mean Well


Figure: Power supply specification

# Schémas électriques

## Schéma électrique du système DRO


Figure: Schéma électrique du système DRO

## Schéma électrique du système DIVIDER

Figure: Schéma électrique du système DIVIDER

# Interface Graphique (sous TouchGFX)

## Interface graphique MENU

On réalise sur TouchGFX l’interface graphique, puis on ajoutera le code des fonctions par la suite (le code de chaque prototypes en 1 dossier de code unique). Cette interface respecte le cahier des charges du client.


## Interface graphique DRO


Figure: Interface graphique du DRO

## Interface graphique DIVIDER


Figure: Interface graphique du DIVIDER

## Interface graphique MMREVS

Figure: Interface graphique du MMREVS

# Développement du prototype

I2C

## Communication entre deux STM32

Il existe différentes façons de communiquer entre deux microcontrôleurs :
- UART (USART)
- SPI (Serial Pe- ripheral Interface)
- I2C (Inter - Integreted Circuit)
Nous comparons les différentes façons de communiquer avec les deux cartes.


Figure: I2C Master/Slave | 37 / 52

## Principe de fonctionnemnt


Figure: Principe de fonctionnement de L’I2C

[b]

Figure: Chronogramme de SDA et SCL | 38 / 52

## Buffers communication I2C


Figure: Buffer que l’ont envoie au slave

[b]

Figure: Code de transmission (master)

## Code de transmission

Figure: Transmission de données (Master)

[b]

Figure: Reception de données (slave)

## Configuration I2C pour le Master et le slave


On fait un adressage pour le slave mais pas pour le master.

Figure: Configuration Master

## Debugger

# Développement du prototype moteurs

## Génération des signaux pour les moteurs

Nous générons un code qui contrôlera les drivers. Pour cela, nous allons générer des signaux de commandes ”STEP” (signal PWM), ”ENABLE” et ”DIRECTION”. Nous utilisons le bloc du registre pour créer le signal PWM.
Nous devons tout d’abord connaitre certaines formules.


Figure: Formules des timers

## Configuration des horloges

TIM1 est lié à APB2. On identifie : APB TIM clock = 100 MHz.


Figure: Configuration de l’horloge

## Configuration de TIMER 1

TIM clock = APB TIM clock / PRESCALER
TIM clock = 100 Mhz / 100 = 1 Mhz Donc on paramètre PRESCALER à : 100-1 (= 99) Frequency = 1 Mhz / ARR Frequency = 1Mhz / 100 = 10 kHz

Figure: Configuration du TIMER 1

## Plus de détails sur le PRESCALER


Figure: Formules des timers

## Visualisation du signal PWM ”STEP”


Figure: Visualisation de ”STEP”

On génère également les signaux ”ENABLE” et ”DIRECTION” qui
sont des signaux binaires. | 48 / 52

## Test du prototype moteur

# Prototype capteur à Incrementation

## Les signaux de commandes

Tous les signaux ont un signal complémentaire afin de réduire les interférences électromagnétiques (EMI) et d’améliorer la qualité de la communication et la robustesse du signal, en particulier sur les longs câbles.
- Signal A : Le signal A+ est un signal carré qui change d’état (haut/bas) à intervalles réguliers lorsque le codeur tourne. le codeur tourne.
- Signal B : le signal B+ est un signal carré déphasée de 90 degrés par rapport au signal A+. Le déphasage de 90 degrés entre A+ et B+ est utilisé pour déterminer le sens de rotation. Si A+ précède B+, la rotation se fait dans un sens, et si B+ précède A+, la rotation se fait dans le sens opposé.
- Signal Z : Le signal Z+ est un signal carré qui génère une seule impulsion par rotation complète du codeur.
Le signal d’index (Z+) est utilisé pour fournir une référence absolue à la position, ce qui permet de recalibrer ou de synchroniser la position avec le codeur.

# Conclusion et suite du projet

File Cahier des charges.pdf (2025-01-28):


Mécaniquement vôtre, EYRAUD Michaël, Rue du puits 15, CH-1345 Le Lieu, Suisse.

EYRAUD Michaël
- Mécaniquement vôtre -
Rue de Puits, 15
1345 Le Lieu
SUISSE
0041.76.451.31.17
mecaniquement.votre.suisse@gmail.com

## DEFINITION

Developpment of few systems to automatise ans simplify functions on old machines.

The systems need to be installed on different machines so the power of the some components can change.

As I mechanician I will do the custom mechinal parts for integration.

All components must be of industrial quality, comply with European standards and be reliable.
We have tou found components that you can order in your country and that I can order in mine too.

The design of interfaces will be provided.

1: A system called “DRO”:

Display and modificate values given by sensors and linear scales, for visual control, on a minimum 10’’ touch screen.

Sensor : RLS RL2ICA2D0D00B00 : https://www.rls.si/eng/rlc2ic-miniature-linear-and-rotary-pcb-level-incremental-magnetic-encoder

Linear scale : RLS MS05DM080A0000 :
https://www.rls.si/eng/ms-scale

Problematics :
- The DRO box will be the control center and user interface panel with screen, control and switches, it have to run 100% autonome with all its necessary elements (like PCB, screen, power supply, …).
- Creating a custom PCB with STM microcontroller.
- The box must be ready to control all other systems :
- The functions of all others systems must be programmed on the microprocessor.
- Female plugs on boxes + cables with two male sockets.
- Preventing possible problems like overheating.
- I need to receive the control box fully wired and working, but not assembled because as a mechanician I will do the integration of components in an aestectics box depending each machine, so, I dont need to receive the control « box ».

2: A system called “Divider”: Control of 2 stepper motors to perform various functions.

Functioning :

From the angular zero bridge and the current linear zero point.

1: Stepper motor No. 1 turns to drive a precision screw/nut system to perform a linear advance cycle including advance of a given value then return to the initial position.

2: Stepper motor No. 2 turns to drive a screw and endless wheel system, to perform angular indexing defined by a given number of divisions, applied to a given angular sector, from its current position to the next position.
The angular position is controlled by an sensor (same as the DRO system) and a circular scale and must be adjusted/corrected as necessary before starting a new cycle of linear motion motor #1.

Sensor : RLS RL2ICA2D0D00B00 : https://www.rls.si/eng/rlc2ic-miniature-linear-and-rotary-pcb-level-incremental-magnetic-encoder Linear scale : RLS MR040G030_N : https://www.rls.si/eng/bonded-radial-incremental-magnetic-rings
Stepper motor:
https://www.soprolec.com/shop/m42hs047-moteur-pas-a-pas-0-44-nm-nema-17-2302?category=8#attr=49,50,51,52,57,%2094,53,54,398,56,397,1747,55
Stepper driver :
https://www.soprolec.com/shop/dmd4022-driver-pas-a-pas-numerique-soprolec-40v-2-2a-1850#attr=548,483,484,485,486,487

Problematics :
- The size of the motors can change, depending on wich machine the divider system will be mounted, so the box can evolve but control code and wiring have to still the same.
- Begin to create and fully assemble a box to run Nema 17 0,5N.m motors (smallest configuration possible).
- The box need to include the unique elements necessary for the operation of the Divider system and must have a female plug to be able to be connected to the first box from the outside.

3 : VFD spindle driving : The third box will include a VFD to drive the 2 speeds spindle motor.

https://www.distrelec.ch/fr/variateur-de-frequence-j1000-2a-400w-380-480v-omron-industrialautomationjza40p2baa/p/30229065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 2df4793f5ce4272c196c1b&itemList=search

Probematics :
- The VFD have to be able drive « Dahlander » two speeds motors.
- The box have to display speed and torque regarding motors specs and pulleys stage (by buttons).
- This box must need to be able to work on DRO system AND independently, displaying informations of speed and torque as DRO on screen, on a simple and independant screen.
- The power of VFD will change depending the spindle motor butthe control code will need to fit any VFD, so I choose to stay on Omron brand.
- Begin to create and fully assemble a box to run a 400W VFD (smallest configuration possible).
- The vfd must be controlled by switches and a potentiometer from the main box.
- Some customers will want a VFD that convert the originals 380V motors to 220V but I dont found high industrial quality brands that provide this tyupes of VFD, so in this cas it’s will be better to directly change the motor to a 220V and take a 220V VFD.
- This box have to work independetely, and display .

## HMI DESIGN :

Loading menu (company logo) :

On every screen header :


(Logo) EYRAUD Michaël - Mécaniquement vôtre | Date Time

## SPLASH / MENU SCREEN

Display : Selection by logos (to draw) and text : DRO – DIVIDER – MM / REVS – CALCUATOR – SETTINGS

DRO | DIVIDER | MM / REVS | CALCUATOR | SETTINGS

## DRO

Display : Number of axis (values from RL2IC sensors) – Functions buttons - Spindle motor informations.

Functions : - ZERO : Set value to 0.
- Ø / R : Double value (Ø = Diameter) or reset to original (R = radius).
- + / - : Add or subtract a value (Show kerybord to give a value, apply, select axis).

(First push on function button, second push on axis to apply)
- Spindle speed

(Motor nominal speed x pulley axle 1 ratio x pulley axe 2 ratio x frequency if speed variator)
- Spindle torque :

((9550 x Motor power (W) / Motor nominal speed (Rpm)) x pulley axle 1 inversed ratio x pulley axe 2 inversed ratio x frequency if speed variator, display « low » between 0Hz and 25Hz.)
- Menu


## DIVIDER

Display : Various functions to control Nema motors - 3 axis DRO for control.
Display values in red when moving after a started cycle.

Functions : - Set divisions
- Set angular sector to divide
- Set divisions rotation speed
- Set feed distance
- Set feed speed
- Set axis to zero

(Click on a value in a white box, show keyboard, enter value, apply.)
- Start / stop cycle
- Menu


## MM / REVS

Display : Various functions to control Nema motors.

Functions : - Set number of revolutions.
- Set revolutions rotation speed.
- Set feed distance by revolutions.
- Spindle motor informations (as DRO screen).

## SETTINGS

Language : English (Default)
Date : 23/10/2023 (entering value)
Time : 7h40 (entering value)
Units : mm / inch
Default opening screen : Splash screen (DRO / Divider / …)

DRO mode : Enabled / Disabed (to see or not on Splash screen)
Number of axis in DRO mode = (to see on display – X, Y, Z, C – Depending of what is plugged)

DIVIDER mode : Enabled / Disabed (to see or not on Splash screen)
Worm wheel and screw ratio =
Feed screw pitch =

Calculator : Enabled / Disabed (to see or not on Splash screen)

Spindle speed values : Enabled / Disabed (to see or not on DRO and mm/Revs screens). Spindle motor nominal speed 1 = (ex : 1400) Rpm
Spindle motor nominal speed 2 = (ex : 2800) Rpm
Spindle motor power = (ex : 3) Cv or (ex : 1500) W
Spindle motor voltage = (ex: 380) V
Spindle motor Amp = (ex : 2,4) A
Spindle motor Frequency = (ex : 50) Hz | From variator

Numbers of pulleys axle : X (example 2)

Pulleys axle 1, number of stages : 3 (3 is as example)
Pulleys axle 1, stage 1 ratio = X mm / X mm (entering pulleys diameter values, example 40mm / 80mm) Pulleys axle 1, stage 2 ratio = X mm / X mm
Pulleys axle 1, stage 2 ratio = X mm / X mm

Pulleys axle 2, number of stages : X (example 3)
Pulleys axle 2, stage 1 ratio = X mm / X mm Pulleys axle 2, stage 2 ratio = X mm / X mm Pulleys axle 2, stage 3 ratio = X mm / X mm

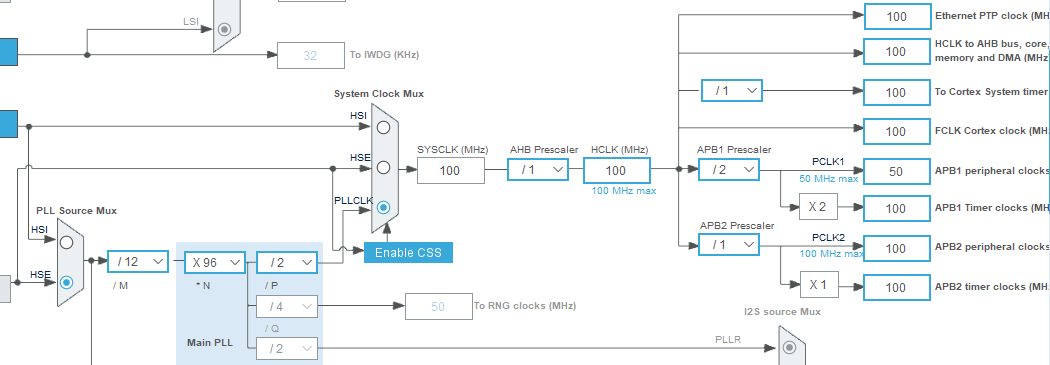
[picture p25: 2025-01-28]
Motor prototype/Clock configuration.png

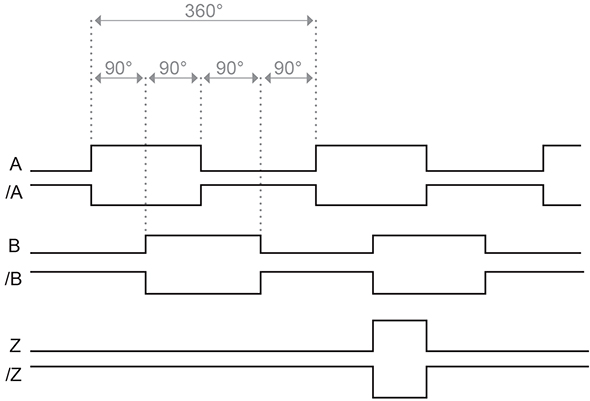
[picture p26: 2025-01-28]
Datasheets/Incremental_pulse-diagrama-b-z.jpg

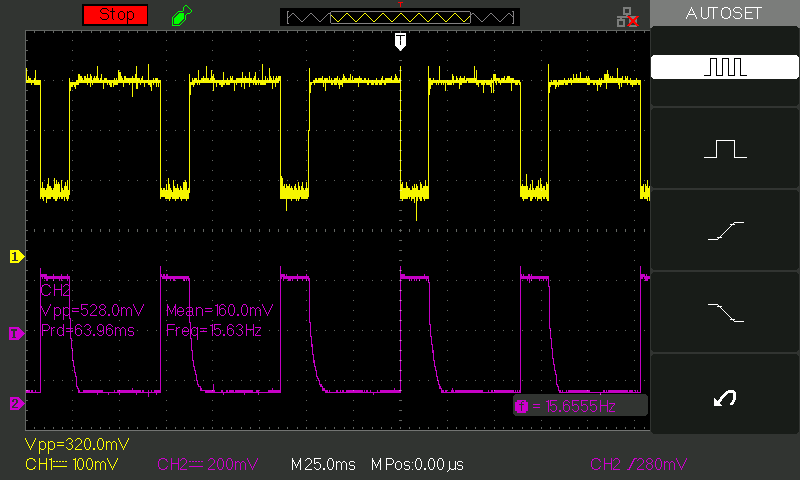
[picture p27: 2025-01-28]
capteur incrementation/B_plus_and_B_minus.BMP

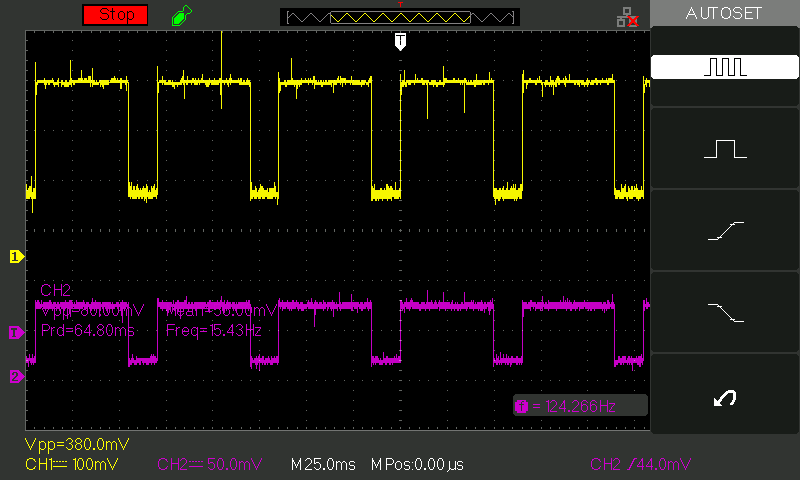
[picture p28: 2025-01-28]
capteur incrementation/A_plus and B_plus.BMP

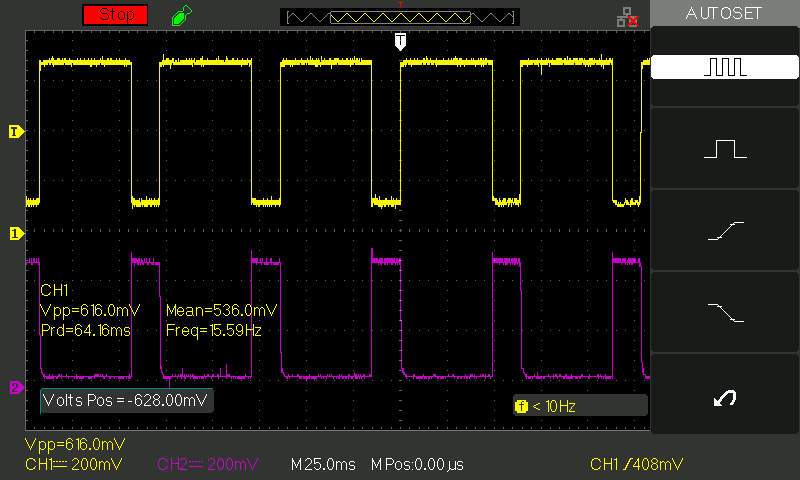
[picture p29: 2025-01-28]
capteur incrementation/A_plus_and_A_minus.BMP

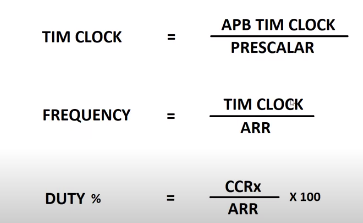
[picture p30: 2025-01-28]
Motor prototype/Formules timer.png
